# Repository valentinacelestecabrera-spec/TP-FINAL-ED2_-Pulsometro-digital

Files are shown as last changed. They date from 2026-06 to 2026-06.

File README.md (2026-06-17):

# TP-FINAL-ED2_Pulsometro-digital
Asignatura: Electrónica Digital II - Universidad Nacional de Córdoba

Integrantes: Cabrera Valentina, Lavena Santiago, Pagani Catalina

Profesor: Marcos Blasco

# 1.Descripcion del proyecto
El proyecto consiste en el desarrolo de un pulsometro usando un microcontrolador (PIC 16F887).
El sistema adquiere la señal a traves de un sensor de pulso cardíaco (HW827), procesa la informacion y calcula la frecuencia cardiaca en Latidos Por Minuto (BPM)
El resultado se muestra en los displays multiplexados. Ademas se genera una indicacion sonora cada vez que se detecta un latido, mediante un buzzer. A su vez, los datos obtenidos se muestran a traves de una interfaz grafica en la PC. 

# 2.Alcances del proyecto  
Este sistema es capaz de: Utilizar interrupciones para temporización y adquisición periódica,transmitir información mediante comunicación UART,generar una señal sonora utilizando un buzzer al detectar un latido,adquirir señales utilizando el conversor Analógico-Digital (ADC) interno del PIC16F887 y calcular la frecuencia cardíaca en BPM.

El sistema no incluye: Almacenamiento permanente de datos,conectividad inalámbrica (Bluetooth o WiFi),registro histórico de mediciones o validación clínica del dispositivo.

# Lineas Futuras
Diseño e implementación de una placa PCB.
Implementación de filtros digitales para mejorar la calidad de la señal.
Incorporación de una pantalla.
Alimentación mediante batería.

# 2. Arquitectura del Sistema: Hardware y Software
aqHardware e Interconexión
Diagrama de Bloques



Esquemático del Circuito realizado en KiCad: 



Descripción del Circuito y Consideraciones de Diseño: 
El sistema está basado en un microcontrolador PIC16F887 alimentado a 5 V. La señal proveniente del sensor óptico infrarrojo es adquirida a través del canal analógico AN0 y convertida a formato digital mediante el módulo ADC interno de 10 bits. El firmware procesa continuamente las muestras para detectar los cruces por umbral asociados a cada latido cardíaco y calcular la frecuencia cardíaca en pulsaciones por minuto (BPM).
Como consideraciones de diseño, se utilizó una resistencia de pull-up en el pin MCLR para garantizar un arranque confiable del microcontrolador y un cristal externo de 4 MHz para proporcionar una referencia de reloj estable. La multiplexación de los displays se implementó mediante interrupciones periódicas del Timer0, permitiendo una visualización continua sin afectar la adquisición de datos del sensor. El procesamiento de la señal incluye un umbral de detección y un período refractario por software para reducir falsas detecciones causadas por ruido o fluctuaciones de la señal óptica.

# Arquitectura de Software (Firmware)

La programación y validación se realizaron mediante simulación en Proteus y en KiCad.
Diagrama de Flujo:
WhatsApp Image 2026-06-17 at 19 08 11
WhatsApp Image 2026-06-17 at 19 08 50

# 3. Especificaciones Eléctricas, Alimentación y Entorno

Parámetros de Alimentación y Consumo

Tensión de operación del sistema: 5V 

Método de alimentación: Alimentacion por USB

Consumo estimado o medido: 

En modo activo (máxima carga, relés/motores encendidos): 150 mA

En modo bajo consumo: 45 mA

Herramientas de software: MPLAB X IDE v5.35 y compilador XC8

Hardware de Programación/Depuración: Bootloader

Configuración de Bits (Fusibles Críticos):

 - Oscilador: Cristal externo de 4MHz

 - Temporizador de vigilancia (WDT): Watchdog timer OFF

Borrado maestro (MCLRE): ENCENDIDO

Periféricos Internos Utilizados: Timer0, ADC, EUSART

Gestión de Interrupciones:

La identificación de la fuente se realiza mediante polling de las banderas correspondientes dentro de la ISR.

En primer lugar se evalúa la bandera del Timer0 (T0IF), ya que este temporizador es responsable de mantener la base de tiempos del sistema, actualizar los contadores de tiempo y realizar el multiplexado de los displays. Posteriormente se verifica la bandera de finalización de conversión ADC (ADIF), utilizada para procesar las muestras provenientes del sensor cardíaco.

# 4. Proceso de Integración y Desarrollo (Común)

Etapa 1 (Validación inicial)
Configuración del oscilador externo de 4 MHz, prueba de funcionamiento básico del PIC16F887 y validación del multiplexado de los displays de siete segmentos.

Etapa 2 (Adquisición y Comunicación)
Implementación y prueba del conversor ADC para la adquisición de la señal del sensor HW827. Configuración de la interfaz UART para transmisión de datos hacia una terminal serial.

Etapa 3 (Integración lógica)
Desarrollo del algoritmo de detección de latidos mediante umbral y período refractario. Implementación del cálculo de frecuencia cardíaca en BPM.

Etapa 4 (Sistema completo)
Integración del sensor, displays, buzzer y UART. Ajuste del umbral de detección, validación funcional del sistema completo y pruebas mediante simulación en Proteus.

#  5. Ensayos, Pruebas y Resultados (Común)

Pruebas Funcionales Realizadas:
Se probo el funcionamiento del sensor para poder configurar el umbral del codigo




Se conectó un potenciómetro a la entrada analógica del microcontrolador PIC16F887 para generar distintos niveles de tensión comprendidos entre 0 V y 5 V. Se comprobó que el conversor analógico-digital realizaba correctamente la conversión de la señal, observándose que el valor digital variaba proporcionalmente con la tensión aplicada

WhatsApp Image 2026-06-17 at 13 22 22

Se estableció una comunicación serie entre el microcontrolador y una computadora mediante un conversor USB-UART. Desde una terminal serie se enviaron distintos comandos, comenzamos comprobando con un comando de encender y apagar un led conectado al pin RB4.

https://github.com/user-attachments/assets/2aee8074-7f5f-411e-81a3-4445ee443086

Se valido la conexion entre la interfaz realizada 



Foto del Prototipo Real:



En funcionamiento:



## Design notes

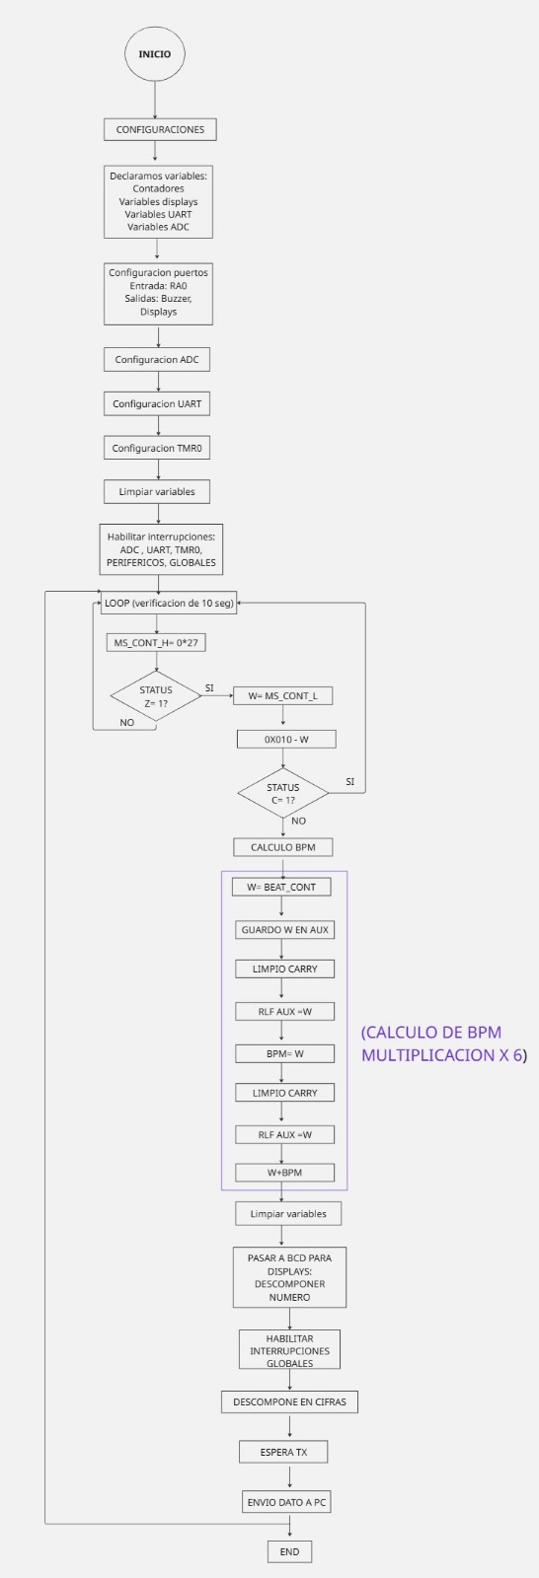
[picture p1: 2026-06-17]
docs/Diagrama_flujos_1.jpeg

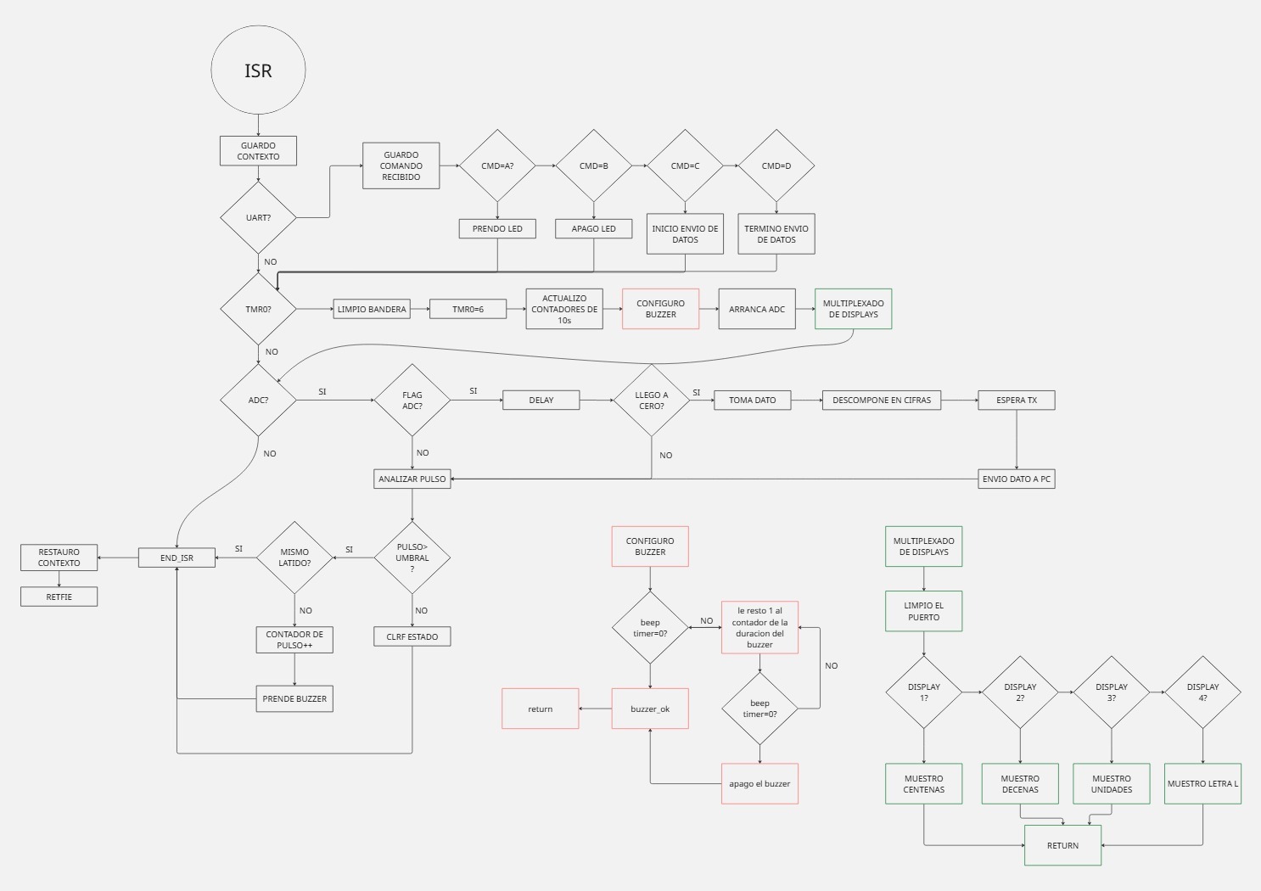
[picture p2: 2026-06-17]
docs/Diagrama_flujos_2.jpeg

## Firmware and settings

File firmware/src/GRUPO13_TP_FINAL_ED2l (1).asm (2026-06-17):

LIST P=16F887
    #INCLUDE <p16f887.inc>

    __CONFIG _CONFIG1, _FOSC_XT & _WDTE_OFF & _PWRTE_ON & _MCLRE_ON & _CP_OFF & _CPD_OFF & _BOREN_OFF & _IESO_OFF & _FCMEN_OFF & _LVP_OFF
    __CONFIG _CONFIG2, _BOR40V & _WRT_OFF

; DEFINICIÓN DE VARIABLES
W_TEMP      EQU 0x70    
STATUS_TEMP EQU 0x71

    CBLOCK 0x20
    ; Contadores
        MS_CONT_L        
        MS_CONT_H           
        BEAT_CONT        
    ; Variables para displays
        UNIDADES         
        DECENAS          
        CENTENAS         
        DISP_ACTIVO      
    ; Resto 
        AUX          
        ESTADO_PULSO
        BEEP_TIMER
        BPM    
    ; Variables UART y ADC continuos
        CMD             
        FLAG_ADC        
        UART_TEMP       ; Reemplaza W_TEMP en subrutinas para no romper ISR
        UART_DELAY      ; Pre-escaler para no saturar el envío por TX
    ENDC

; VECTORES DE INICIO E INTERRUPCIÓN

    ORG 0x0000          
    GOTO INICIO

    ORG 0x0004          
ISR:
    ;Guardar contexto
    MOVWF W_TEMP
    SWAPF STATUS, W
    MOVWF STATUS_TEMP

    ; CHEQUEO RX UART (Recepción de Comandos)
    BANKSEL PIR1
    BTFSS PIR1, RCIF
    GOTO CHK_TMR0

    BANKSEL RCREG
    MOVF RCREG, W
    MOVWF CMD           ; Guardo comando recibido

    MOVLW 'A'
    XORWF CMD, W
    BTFSC STATUS, Z
    GOTO CMD_LED_ON

    MOVLW 'B'
    XORWF CMD, W
    BTFSC STATUS, Z
    GOTO CMD_LED_OFF

    MOVLW 'C'
    XORWF CMD, W
    BTFSC STATUS, Z
    GOTO CMD_ADC_START

    MOVLW 'D'
    XORWF CMD, W
    BTFSC STATUS, Z
    GOTO CMD_ADC_STOP
    GOTO CHK_TMR0

CMD_LED_ON:
    BANKSEL PORTB
    BSF PORTB, 4
    CALL UART_SendOK
    GOTO CHK_TMR0

CMD_LED_OFF:
    BANKSEL PORTB
    BCF PORTB, 4
    CALL UART_SendOK
    GOTO CHK_TMR0

CMD_ADC_START:
    BANKSEL FLAG_ADC
    BSF FLAG_ADC, 0
    CALL UART_SendOK
    GOTO CHK_TMR0

CMD_ADC_STOP:
    BANKSEL FLAG_ADC
    BCF FLAG_ADC, 0
    CALL UART_SendOK
    GOTO CHK_TMR0

    ; CHEQUEO TIMER0 (1ms Multiplexado y Tiempos)
CHK_TMR0:
    BANKSEL INTCON
    BTFSS INTCON, T0IF
    GOTO CHK_ADC        

    BCF INTCON, T0IF    ; Limpiar bandera
    MOVLW d'6'          ; Recargar Timer0 (1ms)
    MOVWF TMR0

    ; Actualizar contadores de 10s
    BANKSEL MS_CONT_L
    INCF MS_CONT_L, F
    BTFSC STATUS, Z
    INCF MS_CONT_H, F
   
    ; Lógica del BUZZER
    BANKSEL BEEP_TIMER
    MOVF BEEP_TIMER, F
    BTFSC STATUS, Z
    GOTO BUZZER_OK
    DECFSZ BEEP_TIMER, F
    GOTO BUZZER_OK	; Me salteo el resto hasta que se tenga q apagar
    BANKSEL PORTB
    BCF PORTB, 0        ; Apagar buzzer al llegar a 0

BUZZER_OK:
    ; Arranco conversión ADC
    BANKSEL ADCON0
    BSF ADCON0, GO

    ; MULTIPLEXADO DISPLAYS
    BANKSEL PORTC
    CLRF PORTC          

    BANKSEL DISP_ACTIVO
    MOVF DISP_ACTIVO, W
    XORLW D'0'
    BTFSC STATUS, Z
    GOTO MOSTRAR_CENTENAS

    MOVF DISP_ACTIVO, W
    XORLW D'1'
    BTFSC STATUS, Z
    GOTO MOSTRAR_DECENAS
    
    MOVF DISP_ACTIVO, W
    XORLW D'2'
    BTFSC STATUS, Z
    GOTO MOSTRAR_UNIDADES
    
    GOTO MOSTRAR_LETRA_L

MOSTRAR_CENTENAS:
    MOVF CENTENAS, W
    CALL TABLA_7SEG          
    MOVWF PORTD                
    MOVLW B'00000001'   ; Enciende Display 1 (RC0)
    MOVWF PORTC                
    MOVLW D'1'
    MOVWF DISP_ACTIVO          
    GOTO CHK_ADC

MOSTRAR_DECENAS:
    MOVF DECENAS, W
    CALL TABLA_7SEG
    MOVWF PORTD                
    MOVLW B'00000010'   ; Enciende Display 2 (RC1)
    MOVWF PORTC                
    MOVLW D'2'
    MOVWF DISP_ACTIVO          
    GOTO CHK_ADC

MOSTRAR_UNIDADES:
    MOVF UNIDADES, W
    CALL TABLA_7SEG
    MOVWF PORTD                
    MOVLW B'00000100'   ; Enciende Display 3 (RC2)
    MOVWF PORTC            
    MOVLW D'3'          
    MOVWF DISP_ACTIVO          
    GOTO CHK_ADC
    
MOSTRAR_LETRA_L:
    MOVLW 0x38          ; L 
    MOVWF PORTD         
    MOVLW B'00001000'   ; Enciende Display 4 (RC3)
    MOVWF PORTC
    CLRF DISP_ACTIVO    
    
    ; CHEQUEO ADC (Fin de conversión)
CHK_ADC:
    BANKSEL PIR1
    BTFSS PIR1, ADIF
    GOTO END_ISR        
    BCF PIR1, ADIF      

    ; ENVÍO UART 
    BANKSEL FLAG_ADC
    BTFSS FLAG_ADC, 0
    GOTO ANALIZAR_PULSO

    ; Enviamos datos cada 50ms para no saturar TX
    BANKSEL UART_DELAY
    DECFSZ UART_DELAY, F
    GOTO ANALIZAR_PULSO
    MOVLW d'10'
    MOVWF UART_DELAY

    BANKSEL ADRESH
    MOVF ADRESH, W
    CALL UART_SendDecimal

ANALIZAR_PULSO:
    ; Evaluamos si hay latido (ADC 8 bits, ADFM=0, Umbral 0x80 = 2.5V)
    BANKSEL ADRESH
    MOVF ADRESH, W
    SUBLW 0x7F          ; Si ADRESH >= 128 (0x80)
    BTFSS STATUS, C
    GOTO ONDA_ALTA       
    GOTO ONDA_BAJA       

ONDA_ALTA:
    BANKSEL ESTADO_PULSO
    MOVF ESTADO_PULSO, W
    XORLW D'1'
    BTFSC STATUS, Z
    GOTO END_ISR        ; Ya estaba alto

    ; Latido nuevo
    INCF BEAT_CONT, F
    MOVLW D'1'
    MOVWF ESTADO_PULSO  
    
    ; Activar BUZZER
    MOVLW D'50'         ; Duración pitido
    MOVWF BEEP_TIMER
    BANKSEL PORTB
    BSF PORTB, 0
    GOTO END_ISR

ONDA_BAJA:
    BANKSEL ESTADO_PULSO
    CLRF ESTADO_PULSO   

END_ISR:
    ; Restaurar contexto
    BANKSEL PORTA
    SWAPF STATUS_TEMP, W
    MOVWF STATUS
    SWAPF W_TEMP, F
    SWAPF W_TEMP, W
    RETFIE

; RUTINAS UART Y CÁLCULOS

UART_SendByte:
    BANKSEL TXSTA
_wait_tx:
    BTFSS TXSTA, TRMT
    GOTO _wait_tx
    BANKSEL TXREG
    MOVWF TXREG
    RETURN

UART_SendOK:
    MOVLW 'O'
    CALL UART_SendByte
    MOVLW 'K'
    CALL UART_SendByte
    MOVLW 0x0A
    CALL UART_SendByte
    RETURN

UART_SendDecimal:
    MOVWF CMD             

    CLRF UART_TEMP
_cent_loop:
    MOVLW .100
    SUBWF CMD, W
    BTFSS STATUS, C
    GOTO _send_cent
    MOVWF CMD
    INCF UART_TEMP, F
    GOTO _cent_loop
_send_cent:
    MOVFW UART_TEMP
    ADDLW '0'
    CALL UART_SendByte

    CLRF UART_TEMP
_dec_loop:
    MOVLW .10
    SUBWF CMD, W
    BTFSS STATUS, C
    GOTO _send_dec
    MOVWF CMD
    INCF UART_TEMP, F
    GOTO _dec_loop
_send_dec:
    MOVFW UART_TEMP
    ADDLW '0'
    CALL UART_SendByte
  
    MOVFW CMD
    ADDLW '0'
    CALL UART_SendByte
  
    MOVLW 0x0A
    CALL UART_SendByte
    RETURN

TABLA_7SEG:
    ANDLW 0x0F         
    ADDWF PCL, F
    RETLW 0x3F ; 0
    RETLW 0x06 ; 1
    RETLW 0x5B ; 2
    RETLW 0x4F ; 3
    RETLW 0x66 ; 4
    RETLW 0x6D ; 5
    RETLW 0x7D ; 6
    RETLW 0x07 ; 7
    RETLW 0x7F ; 8
    RETLW 0x67 ; 9

DESCOMPONER_NUMERO:
    CLRF CENTENAS
    CLRF DECENAS
    MOVF BPM, W
    MOVWF UNIDADES            
LOOP_100:
    MOVLW D'100'              
    SUBWF UNIDADES, W         
    BTFSS STATUS, C           
    GOTO PREP_10
    MOVWF UNIDADES            
    INCF CENTENAS, F          
    GOTO LOOP_100
PREP_10:
    MOVLW D'10'               
    SUBWF UNIDADES, W         
    BTFSS STATUS, C           
    RETURN                    
    MOVWF UNIDADES            
    INCF DECENAS, F           
    GOTO PREP_10

; PROGRAMA PRINCIPAL
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

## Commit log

2026-06-17 Add files via upload
    La simulacion fue realizada mediante Proteus y KiCad
    [esquematico-completo.kicad_sch]
2026-06-17 Update README with power consumption details
